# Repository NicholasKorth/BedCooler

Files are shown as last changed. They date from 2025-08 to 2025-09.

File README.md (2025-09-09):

# Bed Cooler Control System

## Overview

This repository contains the hardware design files and STM32 firmware for a dual-zone bed cooling and heating system. The project is designed to provide temperature control for two independent zones of a mattress using Peltier modules (TECs) for thermoelectric cooling and heating.

The system uses a two-processor architecture:
* **Raspberry Pi Compute Module 5 (CM5):** Serves as the high-level application processor. It is intended to run a user interface (UI) on a MIPI DSI touchscreen, allowing users to set target temperatures, create schedules, and manually control all system components.
* **STM32G474 Microcontroller:** Acts as the real-time hardware controller. It receives commands from the CM5 via UART and directly manages the H-bridges, fans, pumps, solenoids, and all sensor readings.

This board is a development platform for creating a responsive sleeping environment.

---
## License

This project is licensed under the **Creative Commons Attribution-NonCommercial-ShareAlike 4.0 International License**. See the `LICENSE.md` file for details.

You are free to:
* **Share** — copy and redistribute the material in any medium or format.
* **Adapt** — remix, transform, and build upon the material.

Under the following terms:
* **Attribution** — You must give appropriate credit.
* **NonCommercial** — You may not use the material for commercial purposes.
* **ShareAlike** — If you remix, transform, or build upon the material, you must distribute your contributions under the same license as the original.
---
## Hardware Features

### Core Components
* **Microcontroller:** STMicroelectronics **STM32G474RET6**
* **Host Processor:** **Raspberry Pi Compute Module 5 (CM5)**
* **Peltier Drivers:** 2x Texas Instruments **DRV8701ERGER** H-Bridge Gate Drivers, controlling two pairs of TEC-12712 Peltier modules.
* **Audio Amplifier:** Texas Instruments **TAS5805MPWPR** Class-D stereo amplifier with I2S and I2C interfaces, designed for 8-ohm speaker drivers.

### Actuators & Outputs
* **Dual H-Bridges:** For bidirectional (heating/cooling) control of two independent Peltier zones.
* **PWM Fan Control:** Three 4-pin PWM fan headers with tachometer feedback.
* **Pump Drivers:** Two channels for driving 12V water pumps.
* **Solenoid Drivers:** Two channels for controlling 12V solenoid valves.

### Sensors & Inputs
* **Thermistors:** Four dedicated inputs for NTC thermistors to monitor Peltier and water temperatures.
* **Current Sensing:** On-board current sensing circuits for each Peltier H-bridge.
* **Water Presence Sensor:** Input for a water detection sensor.
* **Float Valve Switch:** Input for a reservoir level float switch.
* **H-Bridge Fault Detection:** Dedicated fault inputs from each DRV8701 driver for error handling.

### Connectivity & Peripherals
* **STM32-CM5 Link:** **UART** for command and control.
* **Display:** **MIPI DSI** connector for a touchscreen display.
* **USB Ports:**
    * 1x USB-A 3.0 port.
    * 2x USB-C ports.
* **Video Output:** 1x **HDMI** port.
* **Storage:** On-board **MicroSD card** reader connected to the CM5.

### PCB & Power Specifications
* **Power Input:** Requires a 12V DC power supply capable of providing approximately 350 watts.
* **PCB Layers:** 6-layer board.
* **Design:** Features several impedance-controlled traces for high-speed signals.
* **Stackup:** Designed for JLCpcb stackup JLC06162H-3313.
* **Copper Weight:** 2oz outer copper layers.
* **Via Size:** Minimum via size of 0.2mm hole / 0.35mm diameter.

---
## System Architecture

The division of labor between the two processors is central to the system's design:

* **Raspberry Pi CM5:**
    * Hosts the Linux OS and the user-facing application.
    * Manages the graphical user interface (GUI) on the touchscreen.
    * Handles logic like temperature scheduling, user profiles, and system settings.
    * Sends high-level commands (e.g., "set temperature of zone 1 to 22°C") to the STM32 via UART.
* **STM32G474:**
    * Runs bare-metal or RTOS firmware dedicated to real-time hardware control.
    * Parses commands received from the CM5.
    * Executes the temperature control loop using a hysteresis algorithm.
    * Continuously reads all ADCs for thermistors and current sensing.
    * Generates PWM signals for the Peltier H-bridges and fans.
    * Monitors tachometer feedback to calculate fan RPM.
    * Listens for fault signals from the H-bridge drivers to ensure safe operation.

---
## STM32 Pinout & Peripherals

The following table details the primary pin assignments for the STM32 microcontroller based on the firmware and schematic.

| Function | STM32 Pin | Description |
| :--- | :--- | :--- |
| **Peltier 1 Control** | | |
| Enable (EN) | `PA5` | Enables/Disables the H-Bridge output. |
| Direction (PH) | `PA8` | Controls current direction (Heating/Cooling). |
| nSLEEP | `PA10` | Wakes or sleeps the DRV8701 driver chip. |
| nFAULT (EXTI) | `PA15` | External interrupt input for fault detection. |
| Current Sense (ADC) | `PA4` | Measures current flowing through the Peltier. |
| SNSOUT (Chop Detect) | `PC9` | Input to detect if current chopping is active. |
| **Peltier 2 Control** | | |
| Enable (EN) | `PC3` | Enables/Disables the H-Bridge output. |
| Direction (PH) | `PC2` | Controls current direction (Heating/Cooling). |
| nSLEEP | `PA0` | Wakes or sleeps the DRV8701 driver chip. |
| nFAULT (EXTI) | `PA2` | External interrupt input for fault detection. |
| Current Sense (ADC) | `PA1` | Measures current flowing through the Peltier. |
| SNSOUT (Chop Detect) | `PA3` | Input to detect if current chopping is active. |
| **Sensors (ADC)** | | |
| Thermistor 1 | `PB0` | ADC input for zone 1 temperature. |
| Thermistor 2 | `PB1` | ADC input for zone 2 temperature. |
| Thermistor 3 | `PB2` | ADC input (e.g., water reservoir temp). |
| Thermistor 4 | `PA7` | ADC input (e.g., ambient temp). |
| **Actuators** | | |
| Pump 1 Driver | `PB11` | GPIO output to control the first pump. |
| Pump 2 Driver | `PB14` | GPIO output to control the second pump. |
| Solenoid 1 Driver | `PB15` | GPIO output to control the first solenoid. |
| Solenoid 2 Driver | `PC6` | GPIO output to control the second solenoid. |
| **Fan Control** | | |
| Fan 1 PWM | `PB5` | TIM3_CH2: PWM output for Fan 1 speed. |
| Fan 1 TACH | `PB4` | TIM3_CH1: Input capture for Fan 1 RPM. |
| Fan 2 PWM | `PB7` | TIM3_CH4: PWM output for Fan 2 speed. |
| Fan 2 TACH | `PB6` | TIM8_CH1: Input capture for Fan 2 RPM. |
| Fan 3 PWM | `PB9` | TIM4_CH4: PWM output for Fan 3 speed. |
| **Communication** | | |
| UART TX (to CM5) | `PC4` | Transmits data and responses to the Pi. |
| UART RX (from CM5) | `PC5` | Receives commands from the Pi. |
| **Audio Interface** | | |
| I2S LRCLK | `PA15` | I2S Left/Right Clock (Word Select). |
| I2S SDIN | `PB15` | I2S Serial Data In to the audio amplifier. |
| I2C SCL | `PB8` | I2C Clock for amplifier control. |
| I2C SDA | `PB9` | I2C Data for amplifier control. |

---
## Software Interface (UART API)

The STM32 is controlled by the Raspberry Pi using a serial command set over UART (115200 baud, 8-N-1). All commands should be terminated with a newline character (`\n`).

| Command | Example | Description |
| :--- | :--- | :--- |
| `ping` | `ping` | Checks for connectivity. The STM32 will respond with "pong". |
| `settemp` | `settemp 1 21.5` | Sets the target temperature for a zone (1 or 2) in °C and enables **AUTO** mode. |
| `peltier` | `peltier 1 cool` | Manually overrides a zone (1 or 2) to a specific state: `heat`, `cool`, or `off`. This disables AUTO mode for that zone. |
| `pump` | `pump 2 on` | Turns a pump (1 or 2) `on` or `off`. |
| `solenoid` | `solenoid 1 on` | Turns a solenoid (1 or 2) `on` or `off`. |
| `fan` | `fan 3 75` | Sets a fan's (1-3) speed to a percentage (0-100). |
| `getrpm` | `getrpm 2` | Responds with the current RPM of the specified fan (1 or 2). |
| `therm` | `therm 4` | Responds with the raw ADC value and calculated temperature in Celsius for a thermistor (1-4). |
| `current` | `current 1` | Responds with the raw ADC value from the current sensor for a Peltier zone (1 or 2). |
| `snsout` | `snsout 2` | Reports if current chopping is active for a Peltier zone (1 or 2). |

---
## Build & Deploy Firmware

### Prerequisites

* [STM32CubeIDE](https://www.st.com/en/development-tools/stm32cubeide.html)
* ST-Link programmer/debugger

### Building

1.  Clone this repository.
2.  Open STM32CubeIDE and import the project by navigating to `File > Import... > General > Existing Projects into Workspace`.
3.  Select the cloned repository's root directory.
4.  Build the project using `Project > Build All`.

### Flashing

1.  Connect the ST-Link to the SWD header on the development board.
2.  In STM32CubeIDE, right-click the project and select `Run As > STM32 Application`.
3.  The IDE will automatically build and flash the firmware to the microcontroller.

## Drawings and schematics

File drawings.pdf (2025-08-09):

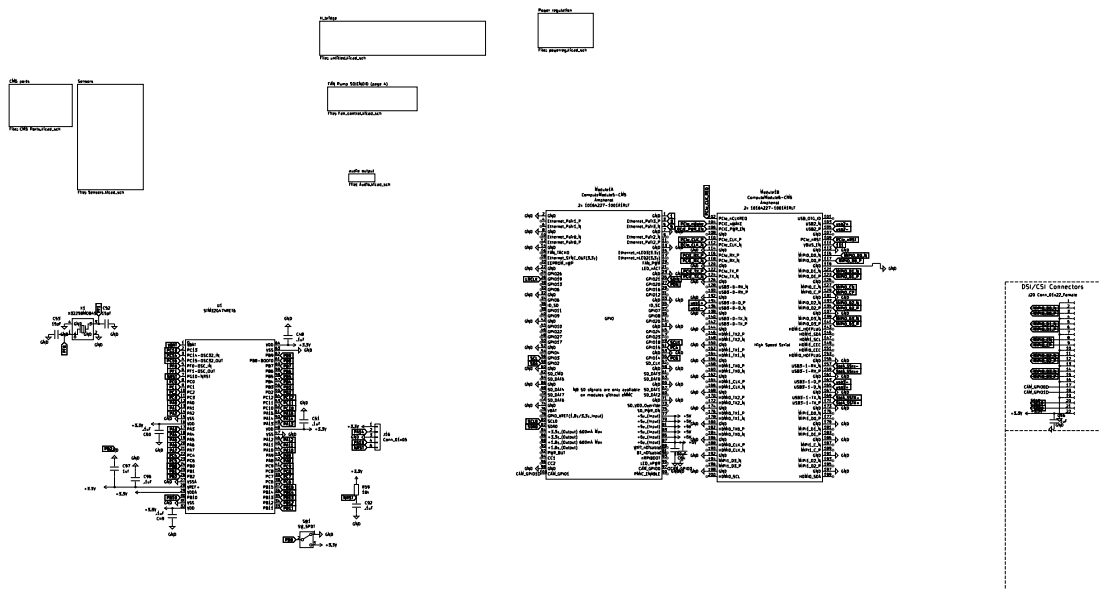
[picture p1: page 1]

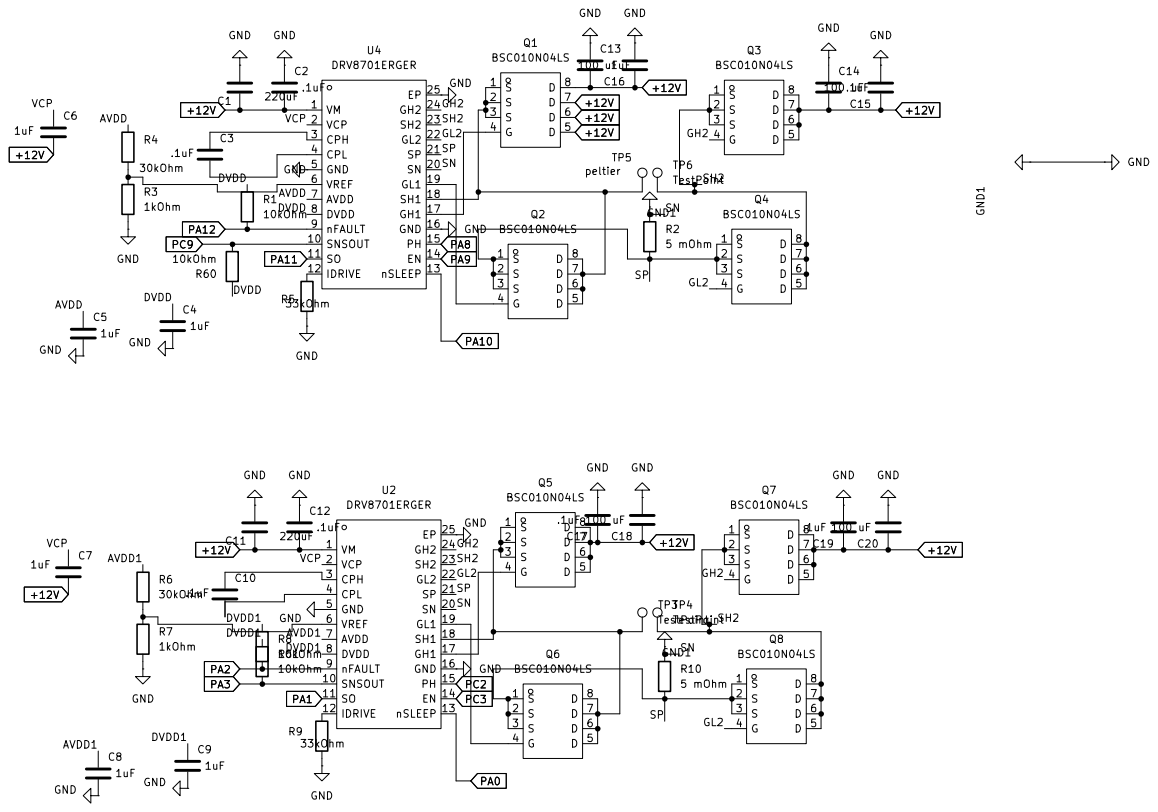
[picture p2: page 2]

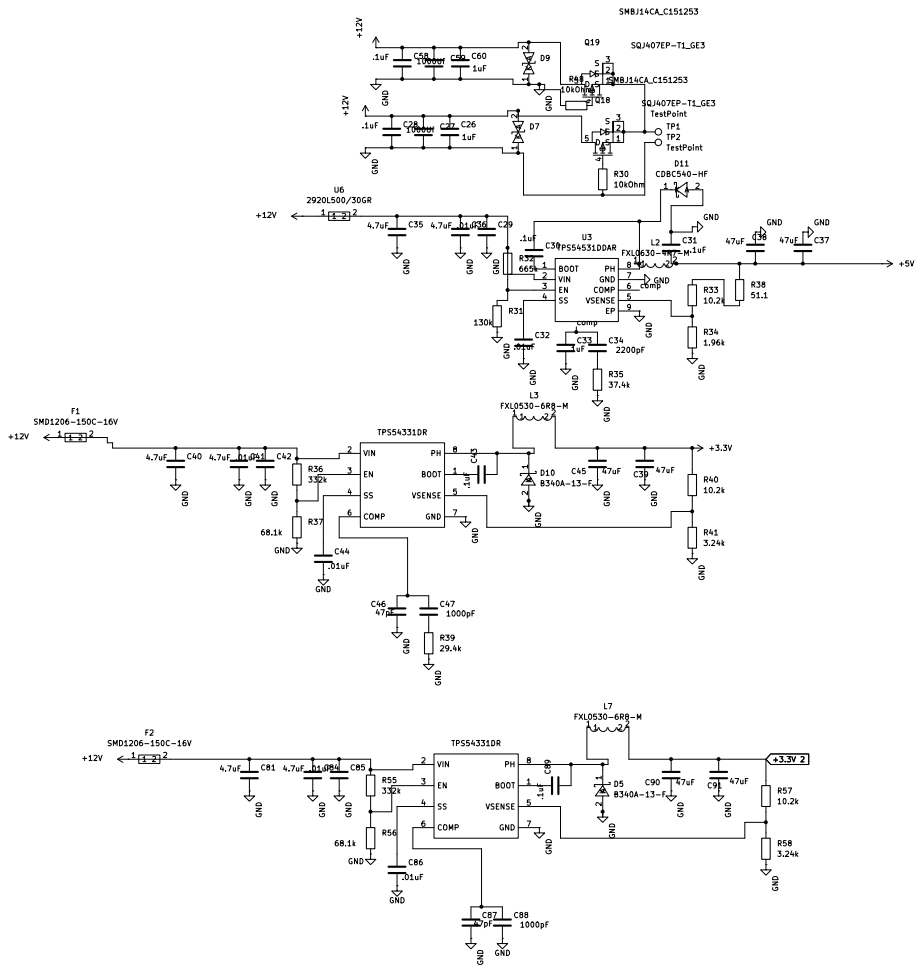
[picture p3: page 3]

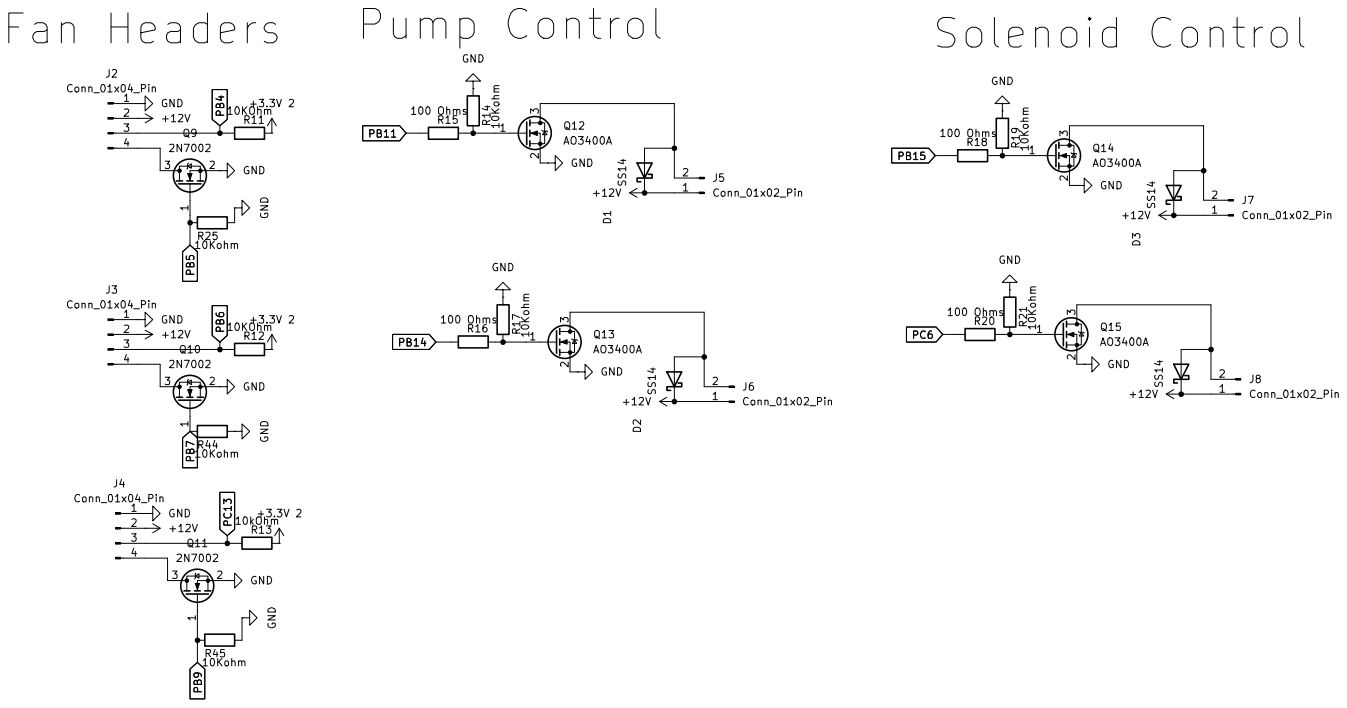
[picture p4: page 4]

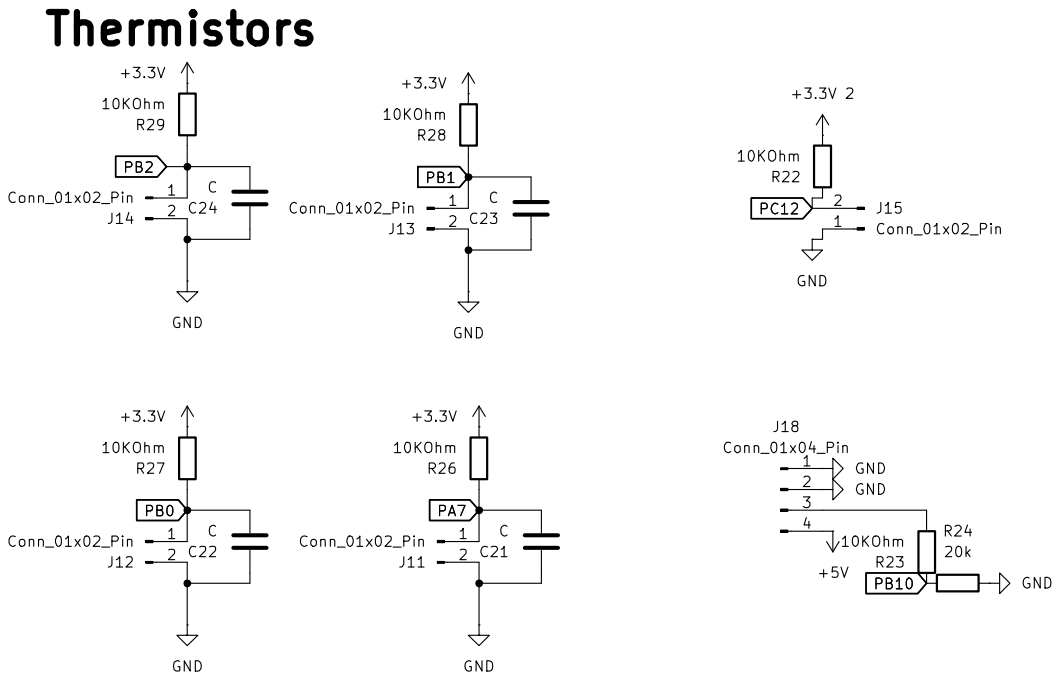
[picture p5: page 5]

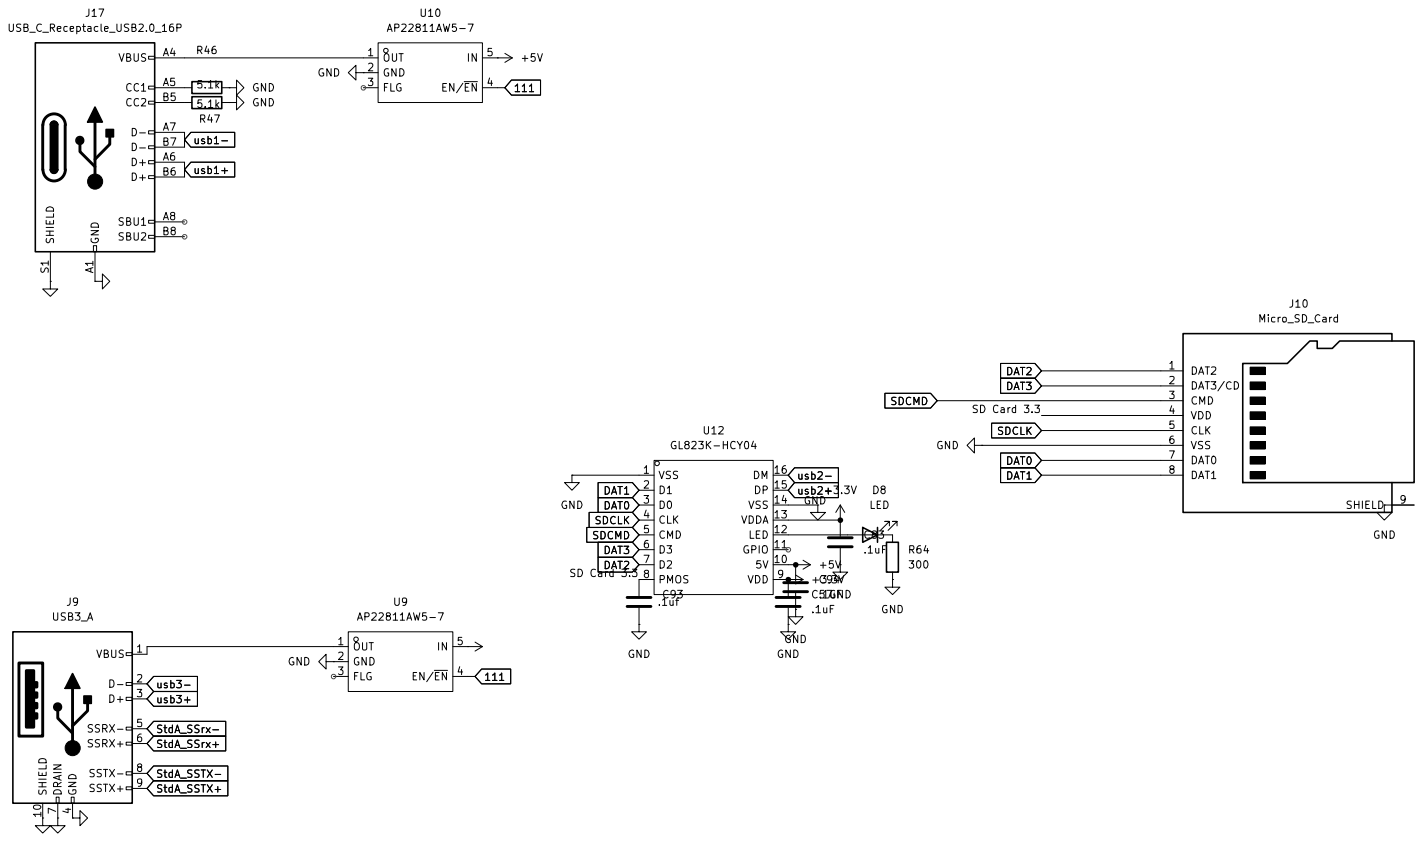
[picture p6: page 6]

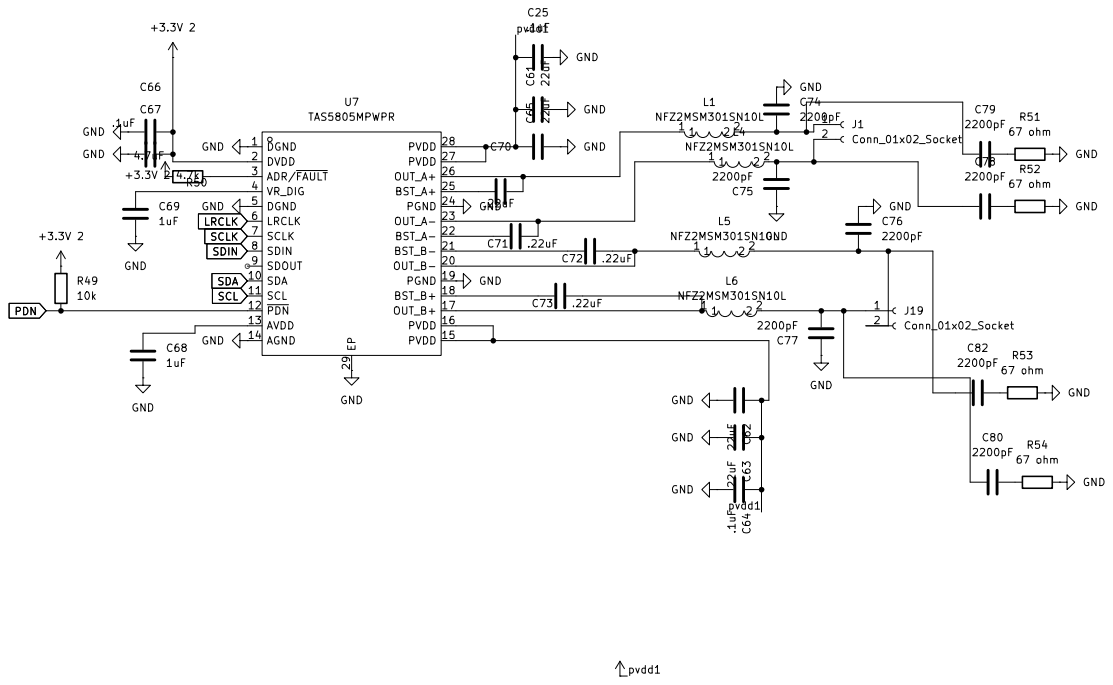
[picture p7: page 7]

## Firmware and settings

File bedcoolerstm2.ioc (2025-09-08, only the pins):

Mcu.UserName=STM32G474RETx
PA0.Signal=GPIO_Output
PA1.Signal=ADC1_IN2
PA10.Signal=GPIO_Output
PA11.Signal=USB_DM
PA12.Signal=USB_DP
PA13.Signal=SYS_JTMS-SWDIO
PA14.Signal=SYS_JTCK-SWCLK
PA2.Signal=GPXTI2
PA3.Signal=GPIO_Input
PA4.Signal=ADC2_IN17
PA5.Signal=GPIO_Output
PA7.Signal=ADC2_IN4
PA8.Signal=GPIO_Output
PA9.Signal=GPIO_Output
PB0.Signal=ADC1_IN15
PB1.Signal=ADC1_IN12
PB11.Signal=GPIO_Output
PB14.Signal=GPIO_Output
PB15.Signal=GPIO_Output
PB2.Signal=ADC2_IN12
PB4.Signal=S_TIM3_CH1
PB5.Signal=S_TIM3_CH2
PB6.Signal=S_TIM8_CH1
PB7.Signal=S_TIM3_CH4
PB9.Signal=S_TIM4_CH4
PC2.Signal=GPIO_Output
PC3.Signal=GPIO_Output
PC4.Signal=USART1_TX
PC5.Signal=USART1_RX
PC6.Signal=GPIO_Output
PC9.Signal=GPIO_Input
PF0-OSC_IN.Signal=RCC_OSC_IN
PF1-OSC_OUT.Signal=RCC_OSC_OUT

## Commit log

2025-08-13 Updated schematic and routed PCB traces
    [10164227-1001a1rlf.stp, BedCooler.kicad_sch, CP_Elec_10x10.5.step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]
2025-08-15 Updated schematic and routed PCB
    [BedCooler.kicad_sch, CM5 Ports.kicad_sch, powerreg.kicad_sch]
